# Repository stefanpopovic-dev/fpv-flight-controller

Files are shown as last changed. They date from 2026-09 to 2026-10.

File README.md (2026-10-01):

# STM32F405 FPV Flight Controller

An open-hardware, 4-layer FPV flight controller board built around the **STM32F405RGT6**, designed in KiCad. Currently at hardware revision **REV3**. Designed to run **Betaflight**.

## Flight video

> 🎥 **Flight video coming soon.**
>
> <!-- Replace this block with the video. Easiest option: edit this README on github.com and drag-and-drop an .mp4 here
>      (GitHub embeds it inline), or link a YouTube video with a thumbnail:
>      [![Flight video](docs/images/photos/quad_front.jpg)](https://www.youtube.com/watch?v=VIDEO_ID) -->

## 3D renders

<p align="center">
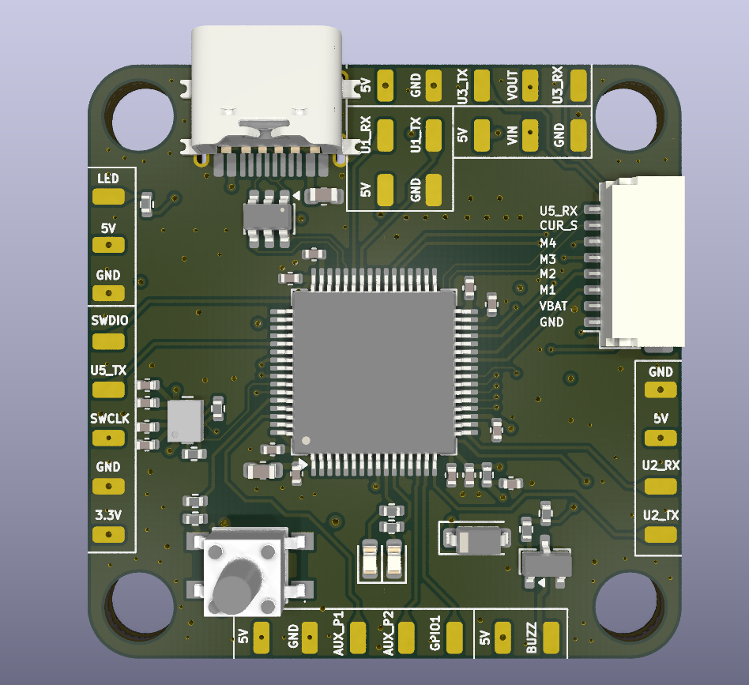
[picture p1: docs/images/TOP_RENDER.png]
Top 3D render
  
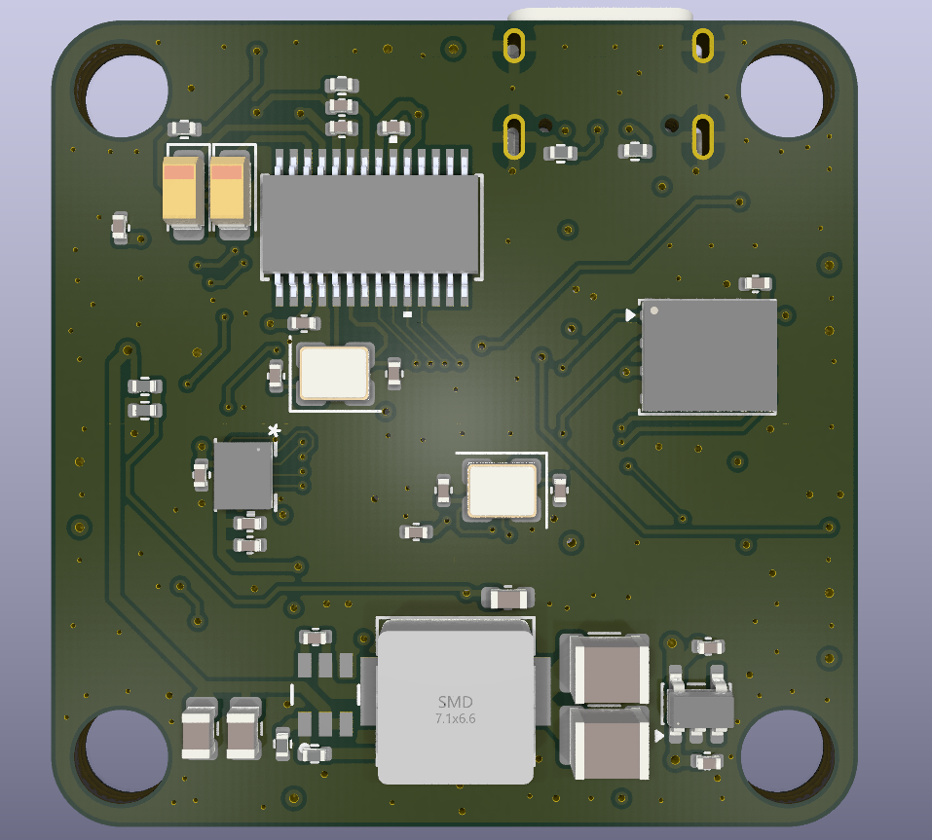
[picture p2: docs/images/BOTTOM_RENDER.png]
Bottom 3D render
  
</p>

## Real build photos

These photos are of the **previous manufactured and tested revision** of this board (see the Disclaimer section below for what changed in REV3).

| Top | Bottom |
|---|---|
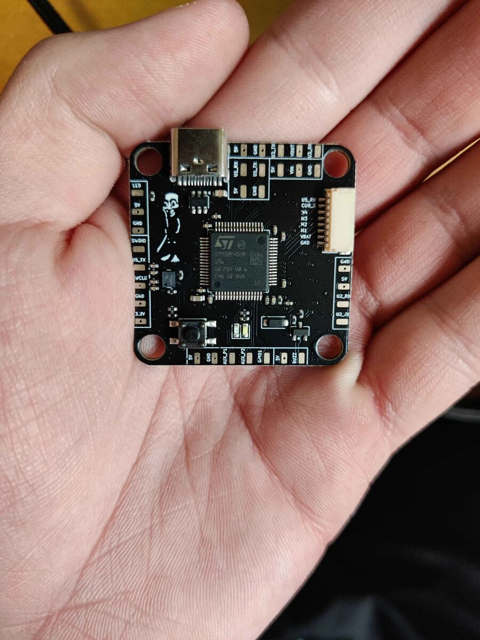
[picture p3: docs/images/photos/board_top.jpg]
Assembled board, top side
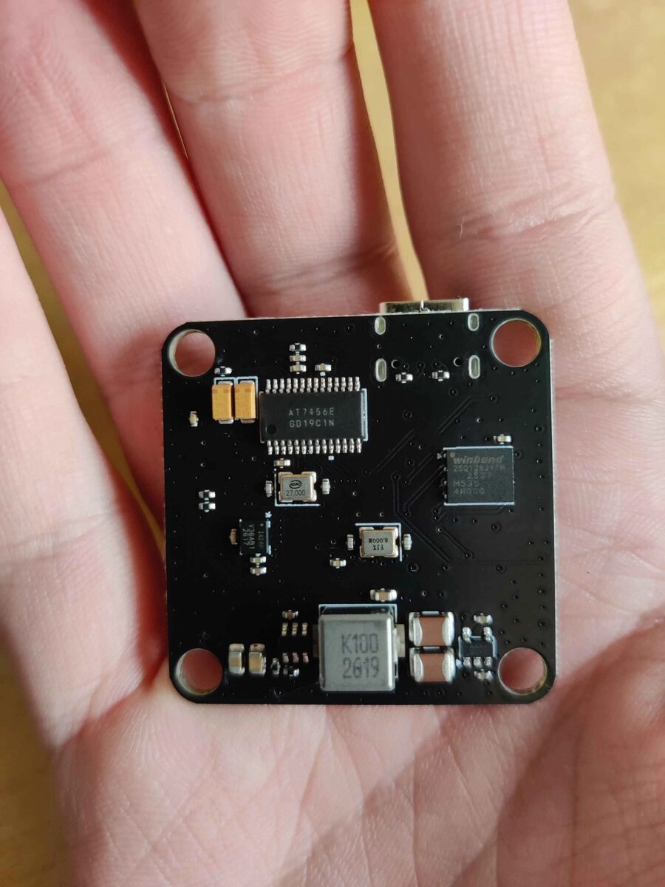
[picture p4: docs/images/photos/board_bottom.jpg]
Assembled board, bottom side
|  |  |

| Installed in the frame | Finished quad (top) | Finished quad (front) |
|---|---|---|
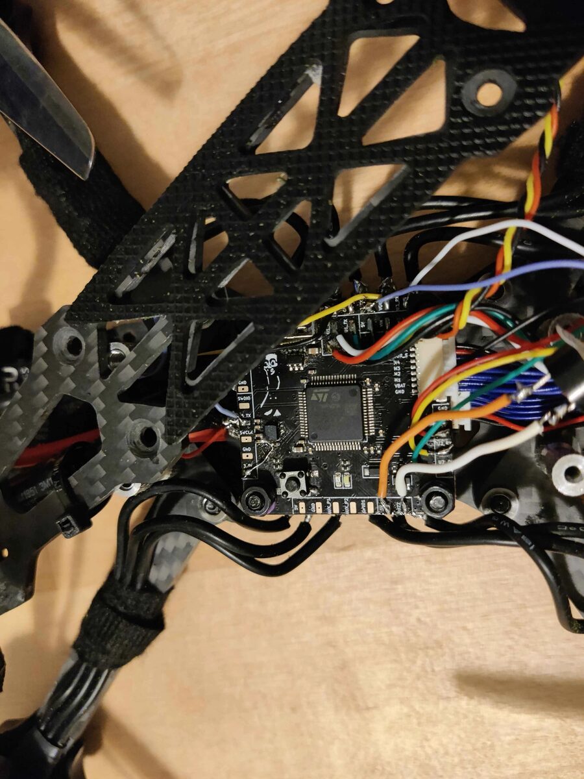
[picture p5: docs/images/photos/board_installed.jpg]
Board wired up in the quad frame
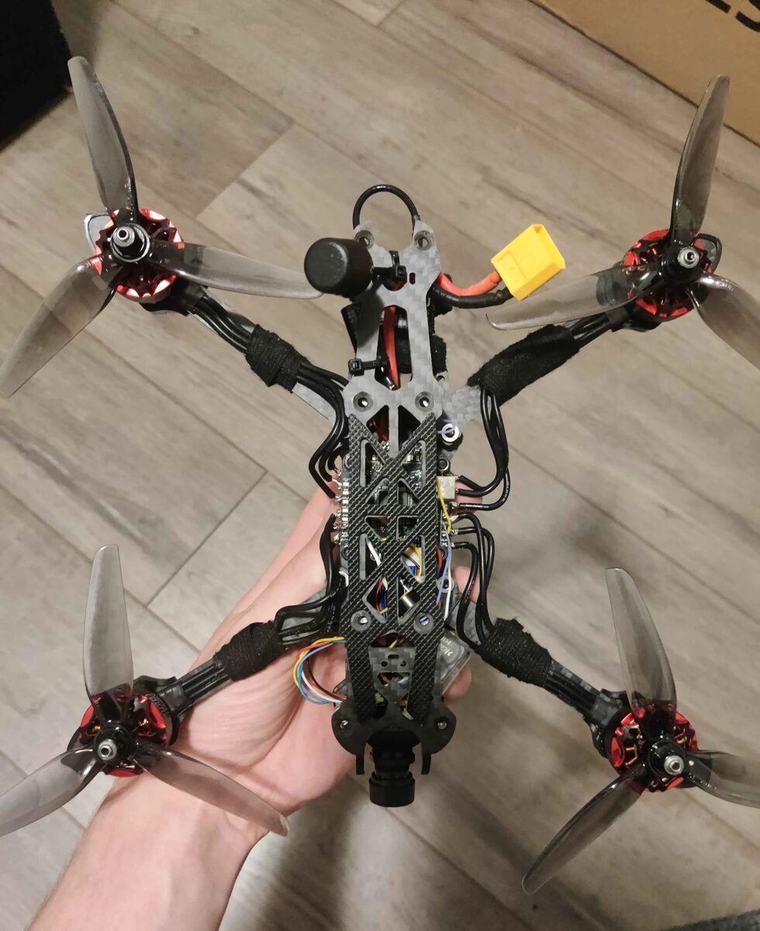
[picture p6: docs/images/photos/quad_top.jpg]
Completed quad, top view
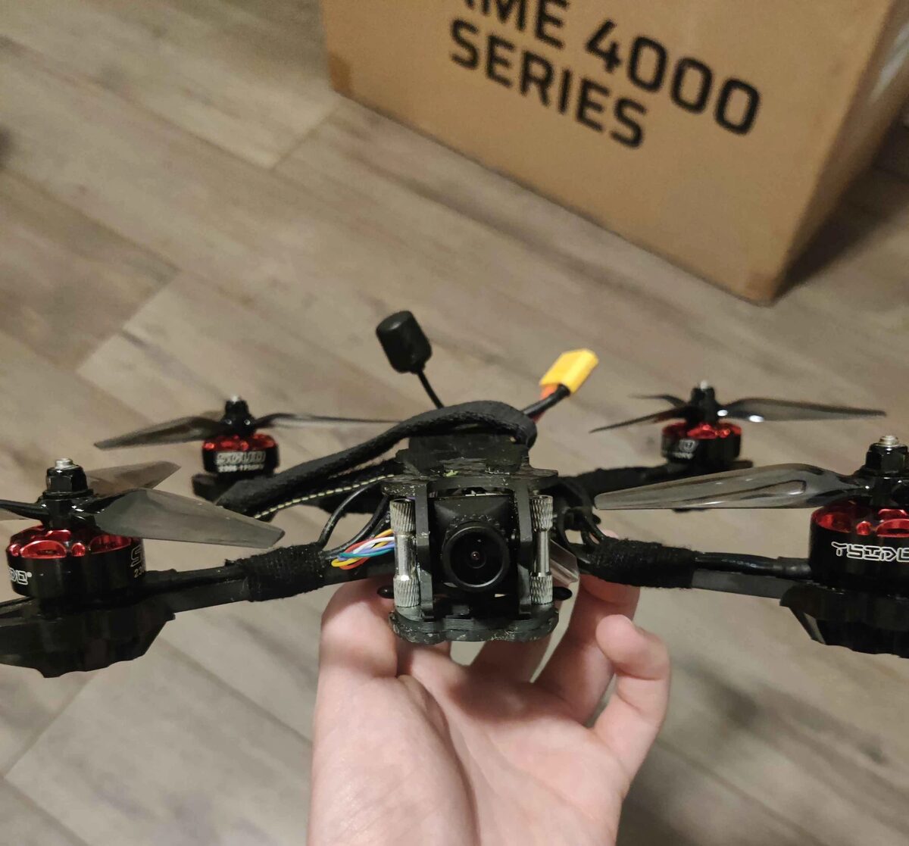
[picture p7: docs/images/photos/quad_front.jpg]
Completed quad, front view with camera
|  |  |  |

## Features

- **MCU:** STM32F405RGT6 (Arm Cortex-M4F, 168 MHz) — the same MCU family used by most Betaflight/iNav AIO flight controllers
- **IMU:** InvenSense ICM-42688-P 6-axis gyro/accelerometer (SPI)
- **Barometer:** Infineon DPS310 for altitude hold / GPS rescue
- **OSD:** MAX7456 analog on-screen display (camera in / VTX out video overlay)
- **Blackbox flash:** Winbond W25Q128JVP, 128 Mbit SPI NOR flash
- **Power:**
  - LMR51635 synchronous buck converter — VBAT down to a regulated 5V rail for the FC and video/VTX peripherals
  - AP2112K-3.3 LDO for the 3.3V digital rail, with a separately filtered +3.3VA analog rail for the IMU
- **USB:** USB-C receptacle with USBLC6-2SC6 ESD protection for DFU flashing / configurator access
- **I/O:** 5 UARTs broken out (UART1, UART2, UART3, UART5), 4 motor signal outputs (M1–M4), current sensor input, buzzer, status LED, boot/reset button, SWD programming header, and general purpose AUX/GPIO pads
- **Board:** 4-layer stack-up (signal / GND plane / power plane / signal)

## Schematic

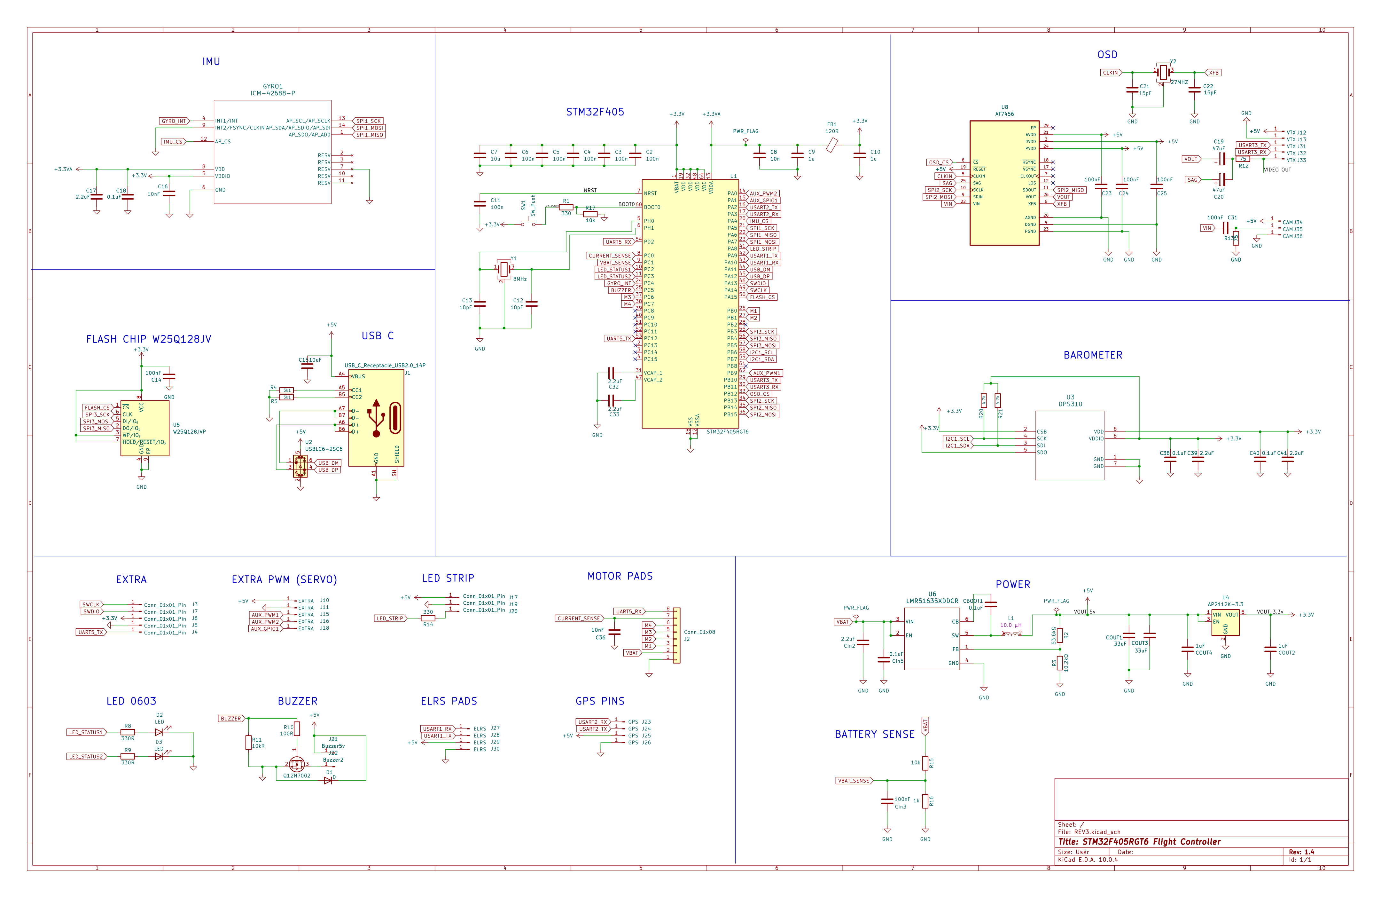
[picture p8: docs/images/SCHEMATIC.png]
Schematic


Full-resolution PDF: [`SCHEMATIC_PDF/REV3.pdf`](SCHEMATIC_PDF/REV3.pdf)

## PCB layout (copper layers)

| Top copper | Bottom copper |
|---|---|
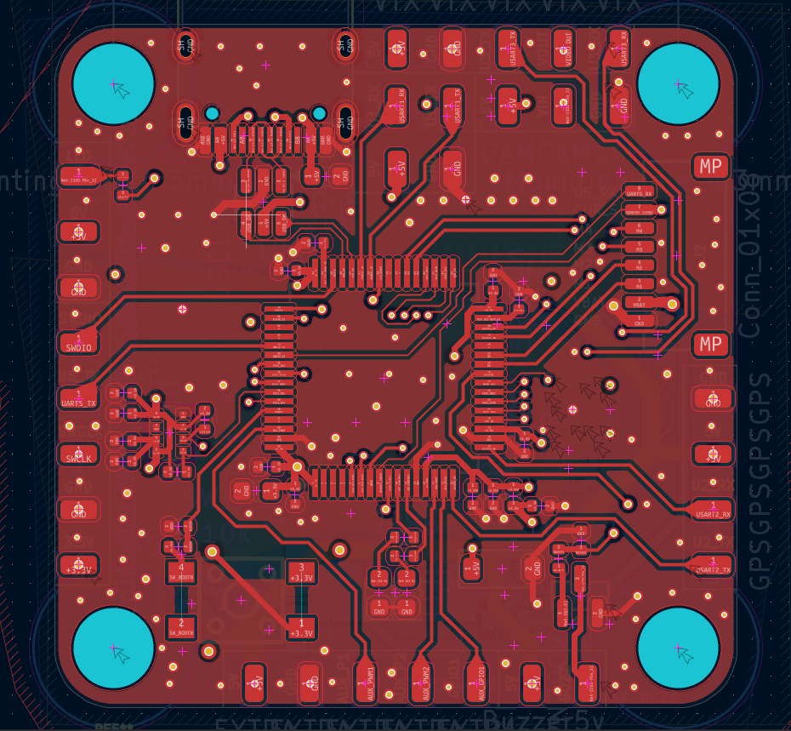
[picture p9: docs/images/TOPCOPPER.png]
Top copper
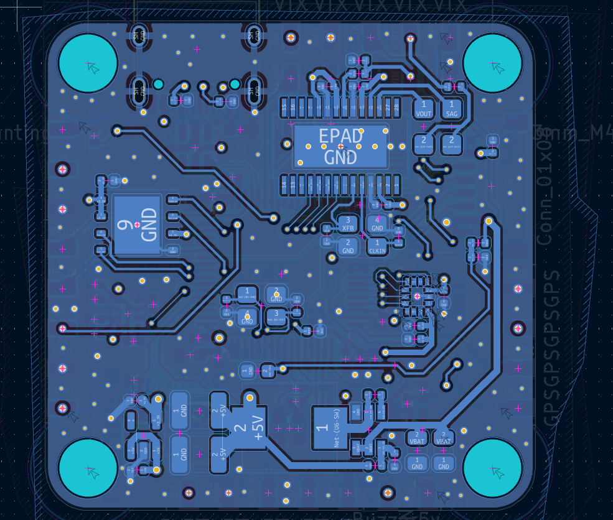
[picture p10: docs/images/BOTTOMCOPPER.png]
Bottom copper
|  |  |

## Connector map

Reference the top-side silkscreen (visible in the top 3D render above) for exact pad locations. Grouped by function:

| Header | Signals |
|---|---|
| SWD / debug | `SWDIO`, `SWCLK`, `GND`, `3.3V`, `U5_TX` |
| Status LED | `LED`, `5V`, `GND` |
| UART1 (GPS / receiver) | `U1_RX`, `U1_TX`, `5V`, `GND` |
| UART3 (VTX / camera) | `U3_TX`, `U3_RX`, `5V`, `GND`, `VOUT` |
| Power in | `VIN`, `5V`, `GND` |
| UART2 | `U2_RX`, `U2_TX`, `5V`, `GND` |
| Motor / ESC connector | `M1`, `M2`, `M3`, `M4`, `VBAT`, `GND`, `CUR_S` (current sense), `U5_RX` (ESC telemetry) |
| AUX | `AUX_P1`, `AUX_P2`, `GPIO1`, `5V`, `GND` |
| Buzzer | `BUZZ`, `5V` |

## Repository structure

```
.
├── hardware/            KiCad 10 project (schematic, PCB, project settings)
│   ├── REV3.kicad_pro
│   ├── REV3.kicad_sch
│   ├── REV3.kicad_pcb
│   ├── REV3.kicad_prl
│   └── fp-lib-table
├── SCHEMATIC_PDF/
│   └── REV3.pdf         Exported schematic PDF
└── docs/
    └── images/          3D renders, copper layer renders, schematic export
        └── photos/      Real photos of the built board and quad
```

## Opening the project

The design was created in **KiCad 10.0**. Open `hardware/REV3.kicad_pro` in KiCad to view/edit the schematic and PCB.

## Firmware compatibility

Built for **Betaflight**. Every IC on this board is natively supported by Betaflight:

- STM32F405RGT6 — supported target MCU family
- ICM-42688-P — supported gyro/accelerometer
- MAX7456 — supported OSD chip
- W25Q128JVP — supported blackbox flash

Since this is a custom PCB (not a stock/off-the-shelf target), it needs a **custom unified target** in Betaflight Configurator with resource mapping matching this schematic's pin assignments: gyro on SPI1 (`PA5`/`PA6`/`PA7`, CS `PA4`), OSD on SPI2 (`PB12`/`PB14`/`PB15`, CS `PB11`), blackbox flash on SPI3 (`PB3`/`PB4`/`PB5`, CS `PA15`), motors `M1`–`M4` on `PB0`/`PB1`/`PC6`/`PC7`, and UART1/2/3/5 as broken out on the connectors above — see the schematic for the full pin list. No target file is included in this repo yet.

## Status / notes

- This repository currently contains the hardware design only (schematic + PCB). No firmware/target file is included yet.
- DRC exclusions present in the board file are inherited from the source project and should be reviewed before fabrication.

## ⚠️ Disclaimer

**This exact revision (REV3) has not been manufactured or tested yet.** It is a corrected revision of a previously manufactured and tested board, so it is very similar to a known-working unit but has not itself been built/verified. The fixes made since the last manufactured/tested version:

- The barometer (DPS310) was not connected to 3.3V — fixed.
- The boot/reset button was tied high and did not function — fixed.

The [real build photos](#real-build-photos) above show that previous tested revision; photos of a REV3 unit will be added once it is built.

## License

Licensed under the [CERN Open Hardware Licence Version 2 - Strongly Reciprocal (CERN-OHL-S v2)](LICENSE). Anyone who manufactures or modifies this design must make their modified source available under the same licence.

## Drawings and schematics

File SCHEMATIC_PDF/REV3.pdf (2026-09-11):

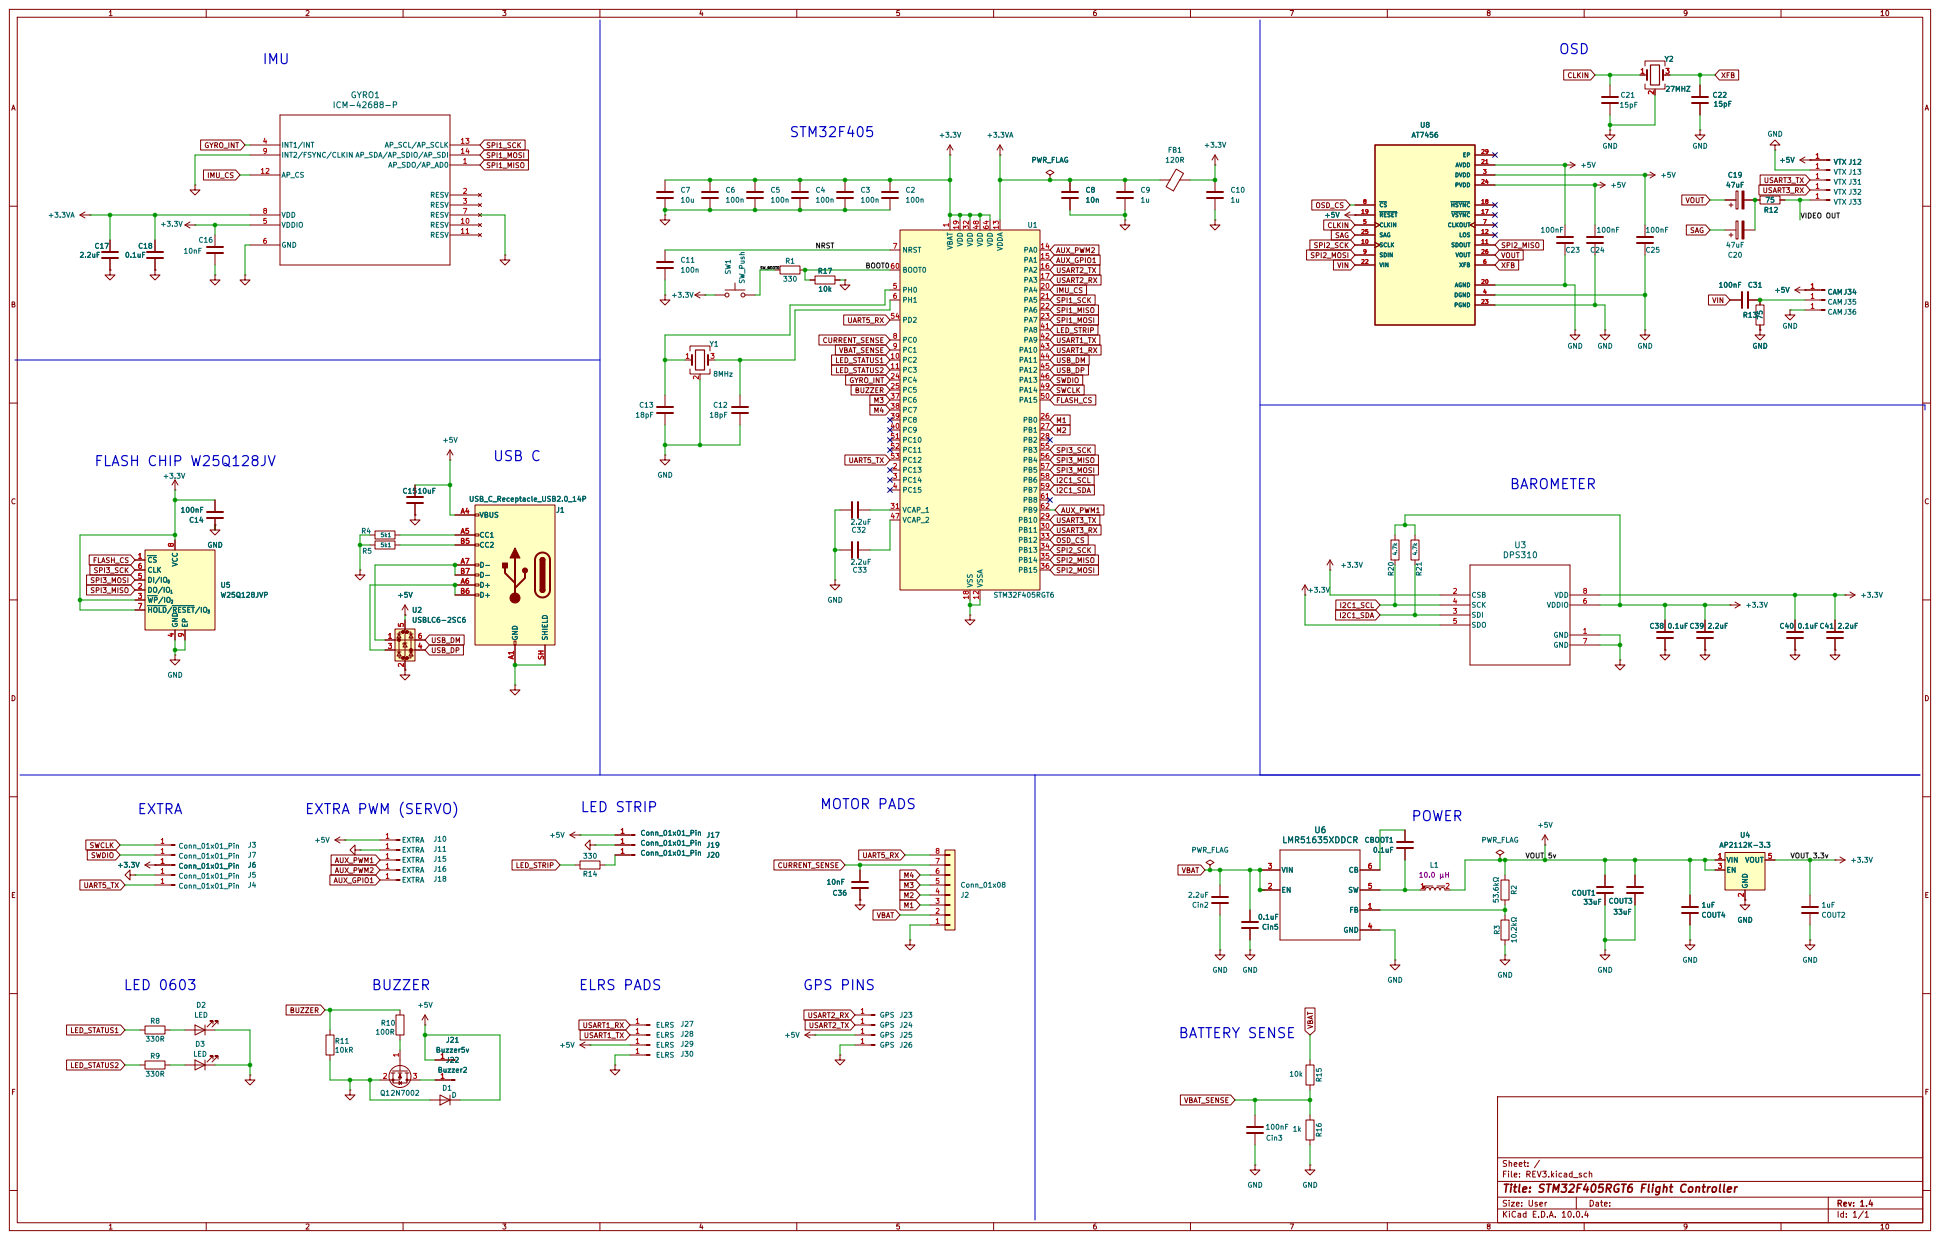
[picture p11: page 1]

4 DI/IO0 5 CLK 6 HOLD/RESET/IO3 7 VCC

SDI 3 | 6 GND

Size: User | Rev: 1.4
KiCad E.D.A. 10.0.4 | Id: 1/1

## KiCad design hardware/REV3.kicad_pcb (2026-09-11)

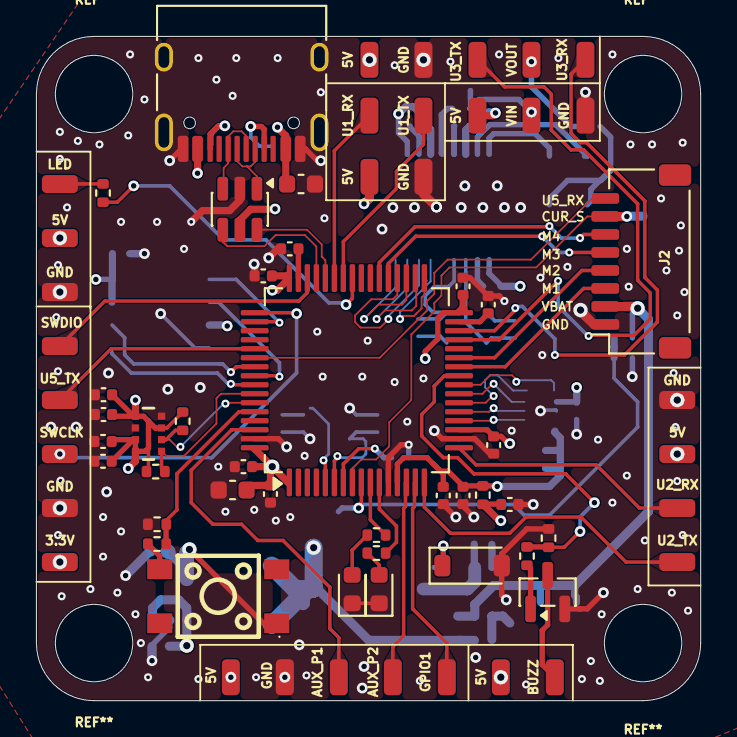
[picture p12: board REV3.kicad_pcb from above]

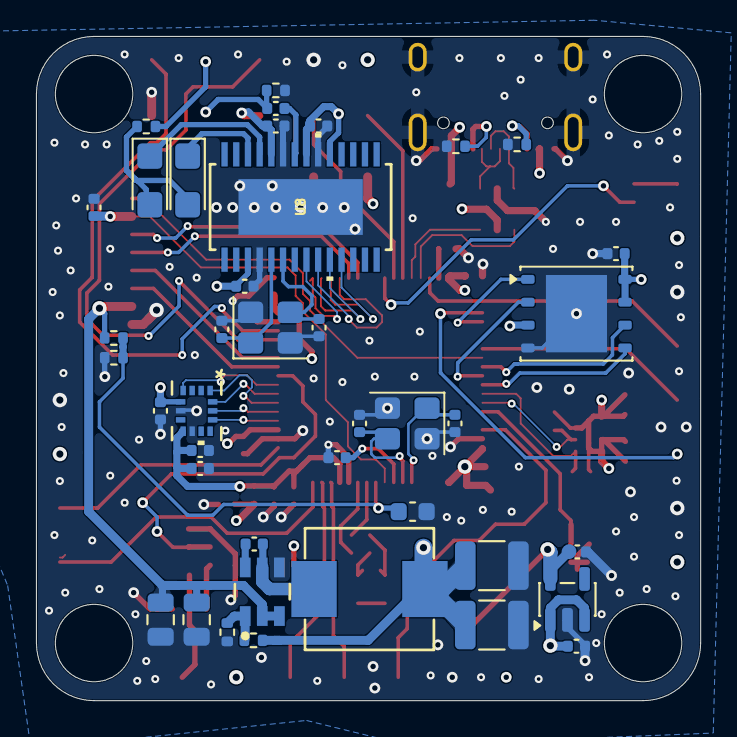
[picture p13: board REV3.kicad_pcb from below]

Board: 4 copper layers, 36.9 x 36.9 mm, 107 parts (40 on the bottom side), 72 nets.

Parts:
3.3V, 5V#7: Conn_01x01_Pin; SolderWirePad_1x01_SMD_1x2mm
5V: VTX; SolderWirePad_1x01_SMD_1x2mm
5V#2: GPS; SolderWirePad_1x01_SMD_1x2mm
5V#3: CAM; SolderWirePad_1x01_SMD_1x2mm
5V#4: EXTRA; SolderWirePad_1x01_SMD_1x2mm
5V#5: Buzzer5v; SolderWirePad_1x01_SMD_1x2mm
5V#6: ELRS; SolderWirePad_1x01_SMD_1x2mm
AUX_P1, AUX_P2: EXTRA; SolderWirePad_1x01_SMD_1x2mm
BUZZ: Buzzer2; SolderWirePad_1x01_SMD_1x2mm
C2, C3, C4, C5, C6, C11: 100n; C_0402_1005Metric
C7: 10u; C_0603_1608Metric
C8: 10n; C_0402_1005Metric
C9, C10: 1u; C_0402_1005Metric
C12, C13: 18pF; C_0402_1005Metric
C14, C23, C24, C25, C31: 100nF; C_0402_1005Metric
C15: 10uF; C_0603_1608Metric
C16, C36: 10nF; C_0402_1005Metric
C17, C32, C33, C39, C41: 2.2uF; C_0402_1005Metric
C18, C38, C40: 0.1uF; C_0402_1005Metric
C19, C20: 47uF; CP_EIA-3216-18_Kemet-A
C21, C22: 15pF; C_0402_1005Metric
CBOOT1: 0.1uF; C_0402_1005Metric
COUT1, COUT3: 33uF; C_1210_3225Metric
COUT2, COUT4: 1uF; C_0402_1005Metric
Cin2: 2.2uF; C_0805_2012Metric
Cin3: 100nF; C_0603_1608Metric
Cin5: 0.1uF; C_0805_2012Metric
D1: D; D_SOD-123
D2, D3: LED; LED_0603_1608Metric
FB1: 120R; R_0402_1005Metric
GND: EXTRA; SolderWirePad_1x01_SMD_1x2mm
GND#2: GPS; SolderWirePad_1x01_SMD_1x2mm
GND#3, GND#7: Conn_01x01_Pin; SolderWirePad_1x01_SMD_1x2mm
GND#4: CAM; SolderWirePad_1x01_SMD_1x2mm
GND#5: VTX; SolderWirePad_1x01_SMD_1x2mm
GND#6: ELRS; SolderWirePad_1x01_SMD_1x2mm
GPIO1: EXTRA; SolderWirePad_1x01_SMD_1x2mm
GYRO1: ICM-42688-P; LGA14_2P5X3X0P91_TDK
J1: USB_C_Receptacle_USB2.0_14P; USB_C_Receptacle_HRO_TYPE-C-31-M-12
J2: Conn_01x08; JST_SH_SM08B-SRSS-TB_1x08-1MP_P1.00mm_Horizontal
L1: MDA7050-100M; IND-SMD_L7.3-W6.6_MHCI06030
LED: Conn_01x01_Pin; SolderWirePad_1x01_SMD_1x2mm
Q1: 2N7002; SOT-23
R1, R14: 330; R_0402_1005Metric
R2: 53.6kΩ; R_0402_1005Metric
R3: 10.2kΩ; R_0402_1005Metric
R4, R5: 5k1; R_0402_1005Metric
R8, R9: 330R; R_0402_1005Metric
R10: 100R; R_0402_1005Metric
R11: 10kR; R_0402_1005Metric
R12, R13: 75; R_0402_1005Metric
R15, R17: 10k; R_0402_1005Metric
R16: 1k; R_0402_1005Metric
R20, R21: 4.7k; R_0402_1005Metric
SW1: SW_Push; SW-SMD_4P-L4.5-W4.5-P3.00-LS6.8
SWCLK: Conn_01x01_Pin; SolderWirePad_1x01_SMD_1x2mm
SWDIO: Conn_01x01_Pin; SolderWirePad_1x01_SMD_1x2mm
U1: STM32F405RGT6; LQFP-64_10x10mm_P0.5mm
U1_RX, U1_TX: ELRS; SolderWirePad_1x01_SMD_1x2mm
U2: USBLC6-2SC6; SOT-23-6
U2_RX, U2_TX: GPS; SolderWirePad_1x01_SMD_1x2mm
U3: DPS310; PG-VLGA-8-1_INF
U3_RX, U3_TX: VTX; SolderWirePad_1x01_SMD_1x2mm
U4: AP2112K-3.3; SOT-23-5
U5: W25Q128JVP; WSON-8-1EP_6x5mm_P1.27mm_EP3.4x4.3mm
U5_TX: Conn_01x01_Pin; SolderWirePad_1x01_SMD_1x2mm
U6: LMR51635XDDCR; DDC0006A-MFG
U8: AT7456; 21-0108G_U28E-5_MXM
VIN: CAM; SolderWirePad_1x01_SMD_1x2mm
VOUT: VTX; SolderWirePad_1x01_SMD_1x2mm
Y1: 8MHz; Crystal_SMD_3225-4Pin_3.2x2.5mm
Y2: 27MHZ; Crystal_SMD_3225-4Pin_3.2x2.5mm

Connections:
+3.3V: 3.3V.1 (Pin_1_1), C2.1, C3.1, C4.1, C5.1, C6.1, C7.1, C10.1, C14.2, C16.1, C38.1, C39.1, C40.1, C41.1, COUT2.2, FB1.2, GYRO1.5 (VDDIO), R20.2, R21.2, SW1.1, SW1.3, U1.1 (VBAT), U1.19 (VDD), U1.32 (VDD), U1.48 (VDD), U1.64 (VDD), U3.2 (CSB), U3.5 (SDO), U3.6 (VDDIO), U3.8 (VDD), U4.5 (VOUT), U5.3 (~WP/IO_{2}), U5.7 (~HOLD/~RESET/IO_{3}), U5.8 (VCC)
+3.3VA: C8.1, C9.1, C17.2, C18.2, FB1.1, GYRO1.8 (VDD), U1.13 (VDDA)
+5V: 5V.1 (Pin_1_1), 5V#2.1 (Pin_1_1), 5V#3.1 (Pin_1_1), 5V#4.1 (Pin_1_1), 5V#5.1 (Pin_1_1), 5V#6.1 (Pin_1_1), 5V#7.1 (Pin_1_1), C15.1, C23.1, C24.2, C25.1, COUT1.2, COUT3.2, COUT4.2, D1.1 (K), J1.A4 (VBUS), J1.A9 (VBUS), J1.B4 (VBUS), J1.B9 (VBUS), L1.2, R2.2, U2.5 (VBUS), U4.1 (VIN), U4.3 (EN), U8.3 (DVDD), U8.19 (~RESET), U8.21 (AVDD), U8.24 (PVDD)
/BOOT0: R1.2, R17.2, U1.60 (BOOT0)
/NRST: C11.1, U1.7 (NRST)
/SW_BOOT0: R1.1, SW1.2, SW1.4
/VIDEO OUT: R12.2, VOUT.1 (Pin_1_1)
AUX_GPIO1: GPIO1.1 (Pin_1_1), U1.15 (PA1)
AUX_PWM1: AUX_P1.1 (Pin_1_1), U1.62 (PB9)
AUX_PWM2: AUX_P2.1 (Pin_1_1), U1.14 (PA0)
BUZZER: R10.2, R11.2, U1.25 (PC5)
CLKIN: C21.1, U8.5 (CLKIN), Y2.1
CURRENT_SENSE: C36.2, J2.7, U1.8 (PC0)
FLASH_CS: U1.50 (PA15), U5.1 (~CS)
GND: C2.2, C3.2, C4.2, C5.2, C6.2, C7.2, C8.2, C9.2, C10.2, C11.2, C12.2, C13.2, C14.1, C15.2, C16.2, C17.1, C18.1, C21.2, C22.2, C23.2, C24.1, C25.2, C32.2, C33.2, C36.1, C38.2, C39.2, C40.2, C41.2, COUT1.1, COUT2.1, COUT3.1, COUT4.1, Cin2.1, Cin3.1, Cin5.1, D1.2 (A), D2.1 (K), D3.1 (K), GND.1 (Pin_1_1), GND#2.1 (Pin_1_1), GND#3.1 (Pin_1_1), GND#4.1 (Pin_1_1), GND#5.1 (Pin_1_1), GND#6.1 (Pin_1_1), GND#7.1 (Pin_1_1), GYRO1.6 (GND), GYRO1.9 (INT2/FSYNC/CLKIN), J1.A1 (GND), J1.A12 (GND), J1.B1 (GND), J1.B12 (GND), J1.SH (SHIELD), J2.1, Q1.2 (S), R3.1, R4.1, R5.1, R11.1, R13.1, R16.2, R17.1, U1.12 (VSSA), U1.18 (VSS), U1.63 (VSS), U2.2 (GND), U3.1 (GND), U3.7 (GND), U4.2 (GND), U5.4 (GND), U5.9 (EP), U6.4 (GND), U8.4 (DGND), U8.20 (AGND), U8.23 (PGND), U8.EPAD, Y1.2 (G), Y1.4 (G), Y2.2 (G), Y2.4 (G)
GYRO_INT: GYRO1.4 (INT1/INT), U1.24 (PC4)
I2C1_SCL: R20.1, U1.58 (PB6), U3.4 (SCK)
I2C1_SDA: R21.1, U1.59 (PB7), U3.3 (SDI)
IMU_CS: GYRO1.12 (AP_CS), U1.20 (PA4)
LED_STATUS1: R8.1, U1.10 (PC2)
LED_STATUS2: R9.1, U1.11 (PC3)
LED_STRIP: R14.2, U1.41 (PA8)
M1: J2.3, U1.26 (PB0)
M2: J2.4, U1.27 (PB1)
M3: J2.5, U1.37 (PC6)
M4: J2.6, U1.38 (PC7)
unnamed: C19.2, C20.2, R12.1
unnamed: D2.2 (A), R8.2
unnamed: D3.2 (A), R9.2
unnamed: J1.A5 (CC1), R4.2
unnamed: J1.B5 (CC2), R5.2
unnamed: J1.A6 (D+), J1.B6 (D+), U2.3 (I/O2)
unnamed: J1.A7 (D-), J1.B7 (D-), U2.1 (I/O1)
unnamed: LED.1 (Pin_1_1), R14.1
unnamed: BUZZ.1 (Pin_1_1), Q1.3 (D)
unnamed: C31.1, R13.2, VIN.1 (Pin_1_1)
unnamed: Q1.1 (G), R10.1
unnamed: C13.1, U1.5 (PH0), Y1.1
unnamed: C12.1, U1.6 (PH1), Y1.3
unnamed: C32.1, U1.31 (VCAP_1)
unnamed: C33.1, U1.47 (VCAP_2)
unnamed: CBOOT1.1, U6.6 (CB)
unnamed: R2.1, R3.2, U6.1 (FB)
unnamed: CBOOT1.2, L1.1, U6.5 (SW)
OSD_CS: U1.33 (PB12), U8.8 (~CS)
SAG: C20.1, U8.25 (SAG)
SPI1_MISO: GYRO1.1 (AP_SDO/AP_AD0), U1.22 (PA6)
SPI1_MOSI: GYRO1.14 (AP_SDA/AP_SDIO/AP_SDI), U1.23 (PA7)
SPI1_SCK: GYRO1.13 (AP_SCL/AP_SCLK), U1.21 (PA5)
SPI2_MISO: U1.35 (PB14), U8.11 (SDOUT)
SPI2_MOSI: U1.36 (PB15), U8.9 (SDIN)
SPI2_SCK: U1.34 (PB13), U8.10 (SCLK)
SPI3_MISO: U1.56 (PB4), U5.2 (DO/IO_{1})
SPI3_MOSI: U1.57 (PB5), U5.5 (DI/IO_{0})
SPI3_SCK: U1.55 (PB3), U5.6 (CLK)
SWCLK: SWCLK.1 (Pin_1_1), U1.49 (PA14)
SWDIO: SWDIO.1 (Pin_1_1), U1.46 (PA13)
UART5_RX: J2.8, U1.54 (PD2)
UART5_TX: U1.53 (PC12), U5_TX.1 (Pin_1_1)
USART1_RX: U1.43 (PA10), U1_RX.1 (Pin_1_1)
USART1_TX: U1.42 (PA9), U1_TX.1 (Pin_1_1)
USART2_RX: U1.17 (PA3), U2_RX.1 (Pin_1_1)
USART2_TX: U1.16 (PA2), U2_TX.1 (Pin_1_1)
USART3_RX: U1.30 (PB11), U3_RX.1 (Pin_1_1)
USART3_TX: U1.29 (PB10), U3_TX.1 (Pin_1_1)
USB_DM: U1.44 (PA11), U2.6 (I/O1)
USB_DP: U1.45 (PA12), U2.4 (I/O2)
VBAT: Cin2.2, Cin5.2, J2.2, R15.1, U6.2 (EN), U6.3 (VIN)
VBAT_SENSE: Cin3.2, R15.2, R16.1, U1.9 (PC1)
VIN: C31.2, U8.22 (VIN)
VOUT: C19.1, U8.26 (VOUT)
XFB: C22.1, U8.6 (XFB), Y2.3

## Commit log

2026-09-11 Add STM32F405 flight controller hardware design (REV3)
    Import the KiCad 10 schematic/PCB for the REV3 STM32F405RGT6-based FPV
    flight controller (ICM-42688-P IMU, DPS310 baro, MAX7456 OSD, W25Q128
    blackbox flash, LMR51635 buck + AP2112K-3.3 LDO power stage), and add a
    README with board renders, feature summary, and connector map.
    Claude-Session: https://claude.ai/code/session_01NcYZJYs4sXtJCwSdQYcunV
    [REV3.kicad_pcb, REV3.kicad_sch]
2026-09-11 Add schematic PDF and untested-revision disclaimer
    Add the exported REV3 schematic PDF under SCHEMATIC_PDF/, render it to
    a PNG for inline display on the README, and note that this revision
    (with the barometer 3.3V and stuck-high reset button fixes applied)
    has not yet been manufactured/tested, unlike the prior board revision.
    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
2026-09-11 Update PCB layout, top copper render, and add vector schematic
    Bring in the updated REV3.kicad_pcb and its regenerated top copper
    render from the latest project export, and add the schematic as an
    SVG (SCHEMATIC_SVG/REV3.svg) alongside the existing PDF, using the
    SVG for the inline README preview since it scales cleanly.
    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
    [REV3.kicad_pcb]
2026-09-11 Drop schematic SVG, keep PDF + PNG preview
    Remove SCHEMATIC_SVG/ and restore the rasterized schematic preview
    (docs/images/SCHEMATIC.png) for the README, linking to the PDF export
    for full resolution. Re-synced hardware/ against the latest project
    export to confirm the PCB, schematic, and project files are current.
    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
2026-09-11 Fix broken image links, clarify layout labels, add Betaflight section
    Update the 3D render image paths to match the renamed files
    (TOP_RENDER.png / BOTTOM_RENDER.png), split the "Board renders" section
    into a "3D renders" section and a "PCB layout (copper layers)" section
    so the copper images aren't mislabeled as generic renders, and add a
    Firmware compatibility section documenting Betaflight support and the
    SPI/motor pin mapping needed for a custom unified target.
    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
2026-09-30 Move schematic section above PCB copper layout in README
    Claude-Session: https://claude.ai/code/session_01MGZN32SQ8ZE5wuNymjhMiQ
